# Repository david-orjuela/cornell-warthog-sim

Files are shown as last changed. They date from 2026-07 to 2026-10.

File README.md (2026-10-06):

# Cornell Warthog UR5e RGB-D Tree Reconstruction

A ROS 2 Humble system for repeatable RGB-D acquisition and colored point-cloud
reconstruction of orchard trees using a Clearpath Warthog, a UR5e arm, and an
eye-in-hand RealSense camera.

## Quickstart

> **Physical-robot warning:** the commands below can move a UR5e. Keep the
> teach pendant and emergency stop within reach, use the lab-approved start
> pose and calibration, verify clearances, and keep an experienced operator
> present. Never begin with an unattended 32-step run.

The field-validated system spans two ROS 2 workspaces:

- this repository provides the `reconstruct` package, capture transaction,
  raw-data preservation, reconstruction, and offline analyses;
- Dawood Ahmed's `tree_scanning_ur5e` repository provides the validated UR5e
  bringup, `recorded_scan_trajectory.json`, and
  `arm_scan_motion/scanning_trajectory` replay executable.

Clone both into the paths used by the tested commands:

```bash
mkdir -p "$HOME/dev"

git clone https://github.com/david-orjuela/cornell-warthog-sim.git \
  "$HOME/dev/cornell-warthog-sim"

git clone https://github.com/dahmedm/tree_scanning_ur5e.git \
  "$HOME/dev/dawood_tree_scanning_ur5e"
```

Build:

```bash
source /opt/ros/humble/setup.bash

cd "$HOME/dev/cornell-warthog-sim"
rosdep install --from-paths src --ignore-src --recursive --yes
python3 -m pip install -r requirements.txt
colcon build --symlink-install

cd "$HOME/dev/dawood_tree_scanning_ur5e"
rosdep install --from-paths src --ignore-src --recursive --yes
colcon build --symlink-install
```

Use a unique `scan_id` in
[`src/reconstruct/config/params.yaml`](src/reconstruct/config/params.yaml)
before every run. Never reuse an earlier dataset directory.

For the Cornell lab network, prepare each terminal in this order:

```bash
source /opt/ros/humble/setup.bash
source "$HOME/dev/cornell-warthog-sim/install/setup.bash"
source "$HOME/dev/dawood_tree_scanning_ur5e/install/setup.bash"
export ROS_DOMAIN_ID=26
```

Terminal 1 — bring up the real UR5e and leave it running:

```bash
ros2 launch arm_scan_motion bringup.launch.py
```

Terminal 2 — start reconstruction with wall-clock time:

```bash
ros2 launch reconstruct scan_tree.launch.py \
  params_file:="$HOME/dev/cornell-warthog-sim/src/reconstruct/config/params.yaml" \
  use_sim_time:=false
```

Terminal 3 — verify the controller and capture interfaces:

```bash
ros2 control list_controllers
ros2 action list -t | grep follow_joint_trajectory
ros2 topic info /tree_scan/capture_request -v
ros2 topic info /tree_scan/capture_result -v
```

Begin with a supervised one-step test:

```bash
ros2 run arm_scan_motion scanning_trajectory --ros-args \
  --params-file "$HOME/dev/cornell-warthog-sim/src/reconstruct/config/params.yaml" \
  -p trajectory_input_path:="$HOME/dev/dawood_tree_scanning_ur5e/recorded_scan_trajectory.json" \
  -p max_steps:=1
```

After validating the interfaces and robot behavior, stop the test, assign a new
`scan_id`, restart the reconstructor, and run the complete validated sequence:

```bash
ros2 run arm_scan_motion scanning_trajectory --ros-args \
  --params-file "$HOME/dev/cornell-warthog-sim/src/reconstruct/config/params.yaml" \
  -p trajectory_input_path:="$HOME/dev/dawood_tree_scanning_ur5e/recorded_scan_trajectory.json" \
  -p max_steps:=32
```

Inspect the result:

```bash
python3 -m json.tool "$HOME/dev/tree_scans/<scan_id>/summary.json"
ls -lh "$HOME/dev/tree_scans/<scan_id>/global_point_cloud.ply"
```

The launch file starts only the reconstructor. It does **not** launch the robot
driver or motion executor, and it has no `execute_motion` argument.

## Project background and authorship

This work was completed in summer 2026 by **David Orjuela**, a University of
Central Florida undergraduate visiting Cornell University's AgRobotics Lab
through an NSF-funded REU collaboration with UCF.

The project began with a broader orchard-simulation objective and then narrowed
to a hardware-first need: collect real leafy-tree geometry that could eventually
be cleaned, meshed, simplified, and used as Gazebo assets.

David inherited Dawood Ahmed's tree-scanning, reconstruction, semantic
segmentation, and skeletonization work. This repository adapts and extends the
geometry-reconstruction portion. Major contributions include:

- migration of the required acquisition and reconstruction path to ROS 2
  Humble;
- synchronized aligned RGB-D processing and TF2 lookup at sensor time;
- numbered move–settle–capture transactions;
- fresh five-frame, zero-aware depth bursts;
- retry and rejection handling that never merges failed attempts;
- raw RGB, depth, intrinsics, TF, joint-state, and point-cloud preservation;
- configurable filtering and bounded coarse-to-fine point-to-plane ICP;
- repeatable offline filter and registration experiments;
- TF-only, incremental ICP, scan-order, and TF-anchored pose-graph baselines;
- six orchard datasets with machine-readable summaries.

The dormant-tree semantic segmentation and skeletonization stages were reviewed
but were not migrated into the final field system. They remain inherited work,
not a claimed deliverable of this repository.

See [`docs/provenance.md`](docs/provenance.md) and
[`docs/inherited_work.md`](docs/inherited_work.md) before redistributing code,
calibration, models, imagery, or reconstructed assets.

## Final status

### Delivered

- [x] ROS 2 Humble aligned RGB-D reconstruction node
- [x] TF2 placement at each sensor timestamp
- [x] Metric colored Open3D point clouds and binary PLY export
- [x] Automated replay of the validated 32-pose UR5e trajectory
- [x] Numbered capture request/result handshake
- [x] Five-frame zero-aware depth bursts
- [x] Up to three fresh attempts at one stationary pose
- [x] Rejected-attempt isolation and preservation
- [x] Per-run configuration and summary JSON
- [x] Per-capture RGB, raw depth, median depth, intrinsics, TF, joint state,
      metadata, and raw camera/base-frame PLY output
- [x] Complete supervised indoor 32-pose reconstruction
- [x] Controlled filter and voxel comparisons from identical saved captures
- [x] TF-only and incremental TF+ICP controls
- [x] Incremental-ICP order-sensitivity experiment
- [x] TF-anchored pose-graph experiment with held-out edges
- [x] Six orchard datasets across five physical trees
- [x] Four complete 32-pose orchard runs and two recoverable partial runs
- [x] Dated technical logbook and operating documentation

### Still open

- [ ] Pin the exact external motion-repository URL, branch, and commit
- [ ] Verify the final `CMakeLists.txt` and `package.xml` from a clean clone
- [ ] Formally validate the camera-to-tool eye-in-hand transform
- [ ] Add acquisition-completeness and sun-corruption metrics
- [ ] Replay outdoor data with TF-only, incremental ICP, and the pose graph
- [ ] Add fixed spatial crops and thin cross-section measurements
- [ ] Validate and record the proposed 42-pose/four-row trajectory
- [ ] Record a complete rosbag audit trail for a future acquisition
- [ ] Mesh, simplify, and package selected trees for Gazebo
- [ ] Resolve licenses and approval for public code/data release

## Results

The month ended with a repeatable field system.

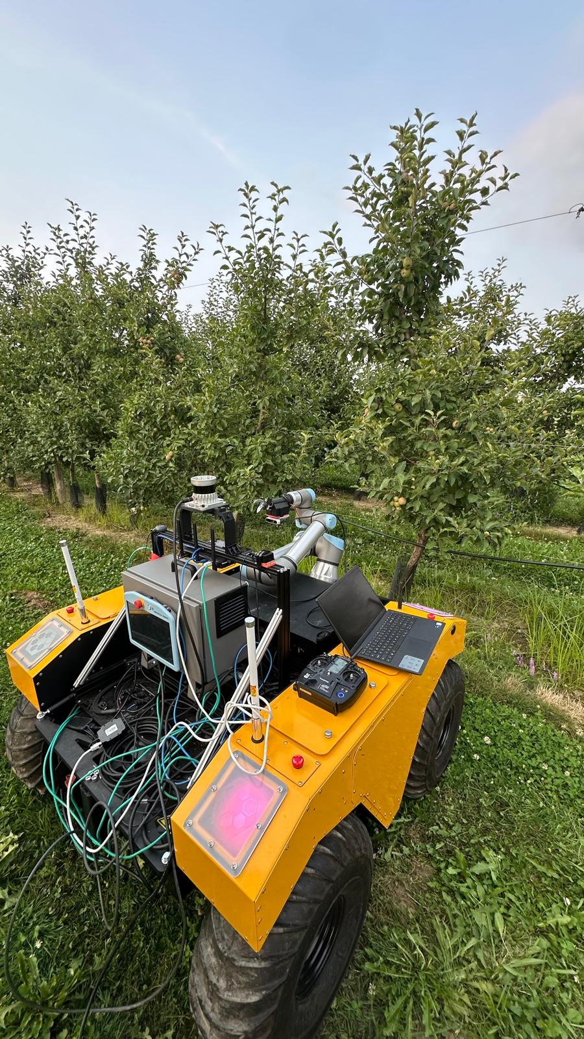
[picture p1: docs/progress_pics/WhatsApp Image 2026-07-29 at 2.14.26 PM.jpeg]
Warthog and UR5e in the Cornell orchard


UR5e performing the field raster scan

### Orchard deployment

Six datasets were collected across five physical trees. The reconstructor
accepted **155 of 157 pose requests** and processed **161 total attempts**.
Four datasets completed all 32 planned poses; two retained useful partial
results.

| Dataset | Pose requests | Accepted | Rejected attempts | Mean ICP fitness | Mean ICP RMSE | Final points | Outcome |
| --- | ---: | ---: | ---: | ---: | ---: | ---: | --- |
| `outdoor_tree_1` | 32 | 32 | 0 | 0.861 | 3.64 mm | 599,999 | Complete; away from sun |
| `outdoor_tree_2` | 32 | 32 | 0 | 0.915 | 3.39 mm | 664,476 | Complete but visually unusable; camera faced sun |
| `outdoor_tree_3` | 32 | 32 | 0 | 0.836 | 3.78 mm | 1,031,782 | Complete; away from sun |
| `outdoor_tree_4` | 14 | 12 | 6 | 0.802 | 4.24 mm | 660,495 | Partial; two poses exhausted all retries |
| `outdoor_tree_5` | 15 | 15 | 0 | 0.810 | 4.13 mm | 737,169 | Partial motion/run interruption |
| `outdoor_tree_6` | 32 | 32 | 0 | 0.862 | 3.78 mm | 1,505,222 | Successful repeat of the final tree |

The first five runs used `max_depth_m: 2.5`; `outdoor_tree_6` used 3.5 m.
All used five-frame depth bursts, at least two valid observations per pixel,
three attempts per pose, 3 mm local/global voxels, statistical outlier removal,
TF initialization, coarse-to-fine ICP, raw preservation, and final PLY export.

`outdoor_tree_2` is an important negative result. It achieved the best ICP
fitness and RMSE while direct sunlight destroyed much of the useful RealSense
depth. Registration metrics describe alignment of surviving points; they do
not prove target completeness or botanical correctness.

### Controlled filter comparison

The same saved 32-capture indoor scan was replayed so every profile used
identical robot poses and RGB-D observations. The table below is the original
6 mm local/5 mm global voxel comparison.

| Profile | Accepted | Final points | Mean fitness | Mean RMSE |
| --- | ---: | ---: | ---: | ---: |
| No outlier removal | 32/32 | 59,065 | 0.9197 | 3.755 mm |
| Current radius | 32/32 | 58,401 | 0.9193 | 3.754 mm |
| Dawood radius | 32/32 | 50,903 | 0.9178 | 3.905 mm |
| Statistical | 32/32 | 59,367 | 0.9206 | 3.731 mm |

The statistical profile had the strongest numerical result by a small margin.
The current-radius profile appeared to preserve slightly more useful fine plant
structure. Dawood's radius profile was too aggressive, and the unfiltered
result retained too much noise. The final field configuration used statistical
filtering at 3 mm local/global voxel size.

### Registration analysis

Good local ICP metrics did not imply a drift-free global reconstruction. In
the reported 4 mm local/global registration experiment, chronological
incremental ICP accepted all 32 captures, with approximately 0.927 mean fitness
and 3.32 mm mean RMSE, but the corrected poses increasingly departed from TF.

| Metric | Incremental TF + ICP | Nominal TF-anchored pose graph |
| --- | ---: | ---: |
| Mean translation deviation from TF | 5.30 mm | 1.99 mm |
| Maximum translation deviation from TF | 13.46 mm | 4.05 mm |
| Mean rotation deviation from TF | 1.01° | 0.108° |
| Maximum rotation deviation from TF | 1.94° | 0.198° |
| Translation-deviation trend | 0.264 mm/frame | approximately zero |
| Mean repeated-pose closure | 0.918 mm / 0.096° | 0.633 mm / 0.046° |
| Mean held-out pose residual | 4.17 mm / 0.686° | 2.91 mm / 0.607° |
| Held-out point-to-plane RMSE | 4.13 mm | 4.20 mm |

Changing only replay order caused mean pose changes of approximately 13.4 mm
and maximum changes near 20 mm. This demonstrated that accumulated-map ICP was
materially order-dependent.

The TF-anchored pose graph removed the frame-wise drift trend and improved pose
consistency, although incremental ICP retained a slightly lower held-out
surface RMSE. TF-only therefore remains a required control, and TEASER++ is
reserved for specific difficult pairwise edges rather than used as a blanket
replacement for the registration architecture.

## System design

```mermaid
flowchart TD
    A["UR5e trajectory reaches pose N"] --> B["Settle and publish UInt32 request N"]
    B --> C["Collect five fresh RGB-D + exact-TF samples"]
    C --> D["Save raw burst and build zero-aware median cloud"]
    D --> E{"Crop, filter, and bounded ICP accepted?"}
    E -->|Yes| F["Fuse cloud, save PLY, publish +N"]
    E -->|No; attempts remain| C
    E -->|No; attempts exhausted| G["Do not fuse; publish -N"]
```

The capture protocol is:

| Interface | Type | Meaning |
| --- | --- | --- |
| `/tree_scan/capture_request` | `std_msgs/msg/UInt32` | Positive pose/request ID |
| `/tree_scan/capture_result` | `std_msgs/msg/Int32` | `+N` accepted; `-N` rejected after all attempts |
| `/tree_scan/scan_finished` | `std_msgs/msg/Bool` | Finalize PLY and summary |
| `/tree_scan/latest_tf_cloud` | `sensor_msgs/msg/PointCloud2` | Current TF-placed, pre-ICP cloud |
| `/tree_scan/global_cloud` | `sensor_msgs/msg/PointCloud2` | Accumulated accepted reconstruction |

The active camera is `camera_jetson`, mounted on the UR5e end effector. It is
not the Warthog-front `camera_0`.

| Input | Validated Cornell topic |
| --- | --- |
| Color | `/sensors/camera_jetson/color/image_raw` |
| Aligned depth | `/sensors/camera_jetson/aligned_depth_to_color/image_raw` |
| Camera intrinsics | `/sensors/camera_jetson/aligned_depth_to_color/camera_info` |
| Robot joints | `/joint_states` |
| Dynamic/static transforms | `/tf`, `/tf_static` |
| Fixed reconstruction frame | `base_link` |

## Validated operating procedure

### 1. Use wall-clock time and the correct ROS domain

Hardware runs used:

```bash
export ROS_DOMAIN_ID=26
```

Keep `use_sim_time:=false` for the UR driver, controller manager, trajectory
controller, camera path, and reconstructor. A mixed clock domain invalidates
timestamped TF lookup.

### 2. Check camera delivery

```bash
ros2 topic hz /sensors/camera_jetson/color/image_raw
ros2 topic hz /sensors/camera_jetson/aligned_depth_to_color/image_raw
ros2 topic echo \
  /sensors/camera_jetson/aligned_depth_to_color/camera_info \
  --once
```

The aligned depth and color images must have matching dimensions. The current
node handles `16UC1` millimeter depth and `32FC1` meter depth.

### 3. Check exact-time TF and joint state

Get the actual depth message frame:

```bash
ros2 topic echo \
  /sensors/camera_jetson/aligned_depth_to_color/image_raw \
  --once \
  --field header.frame_id
```

Then verify:

```bash
ros2 run tf2_ros tf2_echo \
  base_link \
  camera_jetson_color_optical_frame

ros2 topic echo /joint_states --once
```

The joint-state message must contain all six UR5e joints.

### 4. Check the active controller

The field replay targeted:

```text
/joint_trajectory_controller/follow_joint_trajectory
```

Check it before every physical run:

```bash
ros2 control list_controllers
ros2 action list -t | grep follow_joint_trajectory
```

An action name can exist while its controller is inactive. Only one UR driver
and one controller manager should be running.

### 5. Test a stationary capture separately

Use a dedicated preflight `scan_id`, start the reconstructor, and listen for the
result:

```bash
ros2 topic echo /tree_scan/capture_result
```

In another terminal:

```bash
ros2 topic pub --once \
  /tree_scan/capture_request \
  std_msgs/msg/UInt32 \
  "{data: 1}"
```

Expected acceptance:

```text
data: 1
```

For a rejection, inspect:

```text
~/dev/tree_scans/<preflight_scan_id>/raw/capture_0001/capture.json
```

Do not reuse the preflight directory for the final 32-pose run.

### 6. Record an optional rosbag audit trail

The node's raw per-pose archive is sufficient for the provided offline
analyses. A rosbag additionally preserves the complete ROS traffic:

```bash
ros2 bag record \
  -o "$HOME/dev/tree_scans/raw_scan_$(date +%Y%m%d_%H%M%S)" \
  /sensors/camera_jetson/color/image_raw \
  /sensors/camera_jetson/aligned_depth_to_color/image_raw \
  /sensors/camera_jetson/aligned_depth_to_color/camera_info \
  /tf \
  /tf_static \
  /joint_states \
  /tree_scan/capture_request \
  /tree_scan/capture_result \
  /tree_scan/scan_finished
```

### 7. End and verify the run

When the motion executor publishes `/tree_scan/scan_finished`, the reconstructor
writes the final PLY and summary. If a run is interrupted, stop the
reconstructor cleanly with `Ctrl-C`; its shutdown path also writes the current
PLY and summary.

Verify:

```bash
python3 -m json.tool "$HOME/dev/tree_scans/<scan_id>/summary.json"
find "$HOME/dev/tree_scans/<scan_id>/raw" \
  -maxdepth 2 \
  -name capture.json \
  -print
```

`summary.json` reports attempt-based `accepted_percent`. Use
`accepted_capture_requests / completed_capture_requests` for pose-request
success.

## Output layout

```text
~/dev/tree_scans/<scan_id>/
├── global_point_cloud.ply
├── run_config.json
├── summary.json
└── raw/
    ├── capture_0001/
    │   ├── capture.json
    │   ├── frame_00_color.png
    │   ├── frame_00_depth.npy
    │   ├── frame_00_depth.png
    │   ├── ...
    │   ├── selected_color.png
    │   ├── median_depth_m.npy
    │   ├── median_depth_mm.png
    │   ├── median_valid_counts.npy
    │   ├── raw_camera_cloud.ply
    │   └── raw_target_cloud.ply
    └── capture_0001_attempt_02/
        └── ...
```

Every attempt is preserved separately. Only accepted attempts are merged into
`global_point_cloud.ply`.

`capture.json` records:

- request and attempt IDs;
- acceptance state and reason;
- camera intrinsics and encodings;
- every sensor timestamp;
- exact `target_frame <- camera_frame` matrices;
- joint-state snapshots;
- burst pose spread;
- valid-depth fraction;
- raw, cropped, filtered, and global point counts;
- crop bounds;
- ICP fitness, RMSE, and correction;
- processing time.

`run_config.json` preserves the effective ROS parameters used for acquisition.
Offline scripts read this file, not the repository's current `params.yaml`.

## Offline evaluation

No ROS nodes or robot hardware are required after acquisition.

### Filter and TF/ICP comparison

```bash
python3 src/reconstruct/scripts/compare_filters.py \
  "$HOME/dev/tree_scans/<scan_id>" \
  --profiles none current_radius dawood_radius statistical \
  --registration-modes tf_only tf_icp \
  --local-voxel-size-m 0.003 \
  --global-voxel-size-m 0.003
```

Default output:

```text
<scan_id>/filter_comparisons/<timestamp>_voxel_3mm_local_3mm_global/
```

Key outputs are `comparison.csv`, `replay_manifest.json`, per-frame metrics,
closure metrics, diagnostic plots, and one PLY per filter/registration mode.

### Registration experiment

Fast smoke test:

```bash
python3 src/reconstruct/scripts/compare_registration.py \
  "$HOME/dev/tree_scans/<scan_id>" \
  --profiles statistical \
  --graph-priors nominal \
  --shuffle-count 1
```

Full indoor experiment with known repeated poses:

```bash
python3 src/reconstruct/scripts/compare_registration.py \
  "$HOME/dev/tree_scans/indoor_model_tree_2" \
  --profiles statistical \
  --closure-pairs 3:12,13:22,23:32 \
  --local-voxel-size-m 0.004 \
  --global-voxel-size-m 0.004
```

If request IDs differ, omit `--closure-pairs`; the script attempts automatic
TF-based detection.

See
[`docs/evaluation/REGISTRATION_EVALUATION.md`](docs/evaluation/REGISTRATION_EVALUATION.md)
for outputs and interpretation. Run either analysis script with `--help` for
its complete CLI.

## Configuration

The checked-in
[`src/reconstruct/config/params.yaml`](src/reconstruct/config/params.yaml)
contains the final field-era configuration. The most consequential values are:

| Parameter | Field value | Purpose |
| --- | ---: | --- |
| `depth_burst_size` | 5 | Fresh samples at each stationary pose |
| `depth_burst_min_valid_samples` | 2 | Minimum nonzero observations per pixel |
| `capture_max_attempts` | 3 | Fresh bursts before final rejection |
| `capture_retry_delay_sec` | 0.25 s | Delay between attempts |
| `min_depth_m` | 0.30 m | Conservative D435 validity guard |
| `max_depth_m` | 3.50 m | Final field range; first five runs used 2.50 m |
| `local_voxel_size_m` | 0.003 m | Per-capture downsampling |
| `global_voxel_size_m` | 0.003 m | Accumulated-cloud downsampling |
| `outlier_filter_mode` | `statistical` | Final field filter |
| `use_icp` | `true` | TF placement followed by bounded refinement |
| `capture_timeout_sec` | 60 s | Includes reconstruction-side retries |
| `abort_on_capture_rejection` | `false` | Preserve partial scans after a failed pose |

The full reference, including every reconstructor, registration-scale, replay,
and analysis option, is in
[`docs/PARAMETER_REFERENCE.md`](docs/PARAMETER_REFERENCE.md).

## Repository map

| Path | Status | Purpose |
| --- | --- | --- |
| `README.md` | Active | Clone/build/run/results entry point |
| `requirements.txt` | Active | Tested non-ROS Python dependencies |
| `src/reconstruct/scripts/pointcloud_processing.py` | Active | Capture-triggered ROS 2 RGB-D reconstruction node |
| `src/reconstruct/reconstruct/pc_utils.py` | Active | Open3D-to-ROS 2 `PointCloud2` conversion |
| `src/reconstruct/launch/scan_tree.launch.py` | Active | Loads the reconstructor and parameter file |
| `src/reconstruct/config/params.yaml` | Active | Reconstructor and motion-handshake configuration |
| `src/reconstruct/scripts/compare_filters.py` | Active offline tool | Same-capture filter and TF/ICP replay |
| `src/reconstruct/scripts/compare_registration.py` | Active research tool | Order tests and TF-anchored pose-graph comparison |
| `src/reconstruct/scripts/motion_planner.py` | Experimental; archive | Unvalidated cuRobo migration using the obsolete `/capture_alert` protocol |
| `src/reconstruct/scripts/old_pointcloud_processing.py` | Legacy; archive | Earlier reconstruction implementation; not the field node |
| `src/reconstruct/scripts/REGISTRATION_EVALUATION.md` | Move/replace | Superseded by `docs/evaluation/REGISTRATION_EVALUATION.md` |
| `src/reconstruct/README.md` | Active package guide | Package-specific interfaces and commands |
| `ros1-reconstruction/` | Frozen legacy | Original ROS 1 material; ignored by colcon |
| `docs/IMPLEMENTATION_GUIDE.md` | Active deep guide | Capture design, raw archive, crop, clock, calibration, and controller notes |
| `docs/PARAMETER_REFERENCE.md` | Active | Complete parameter and analysis CLI reference |
| `docs/HANDOFF_CHECKLIST.md` | Active until final tag | Cleanup, provenance, clean-clone, and release checks |
| `docs/evaluation/REGISTRATION_EVALUATION.md` | Active | Registration experiment procedure and outputs |
| `docs/logbook/` | Historical evidence | Dated development, debugging, and field notes |
| `docs/project_charter.md` | Historical planning snapshot | July 21 scope; final outcome is documented here |
| `docs/migration_inventory.md` | Historical migration snapshot | ROS 1/ROS 2 and inherited-work inventory |
| `docs/inherited_work.md` | Active provenance | Ownership and disposition of inherited components |
| `docs/provenance.md` | Active provenance | Sources, authorship, licensing, and release questions |
| `docs/archive/` | Historical | Superseded plans and handoff questions |
| `docs/progress_pics/` | Curated documentation media | Robot, reconstruction, and field evidence |

`CMakeLists.txt`, `package.xml`, `resource/reconstruct`, and
`reconstruct/__init__.py` are ROS 2 package/build metadata. Verify them through
the clean-clone test in the handoff checklist.

## Troubleshooting

### Capture request is published but no result arrives

1. Confirm all three RGB-D inputs are publishing.
2. Confirm their timestamps advance and their dimensions match.
3. Verify exact-time TF from `base_link` to the camera optical frame.
4. Check laptop/Jetson clock synchronization.
5. Allow the configured 60 seconds for all three attempts.
6. Inspect the newest `capture.json` and reconstructor log.

Earlier 15–20 second motion-side timeouts were shorter than a full retry cycle;
one measured final response arrived after approximately 22.8 seconds.

### `TF unavailable` or no base-frame cloud

- use `ROS_DOMAIN_ID=26` on the Cornell system;
- confirm the robot driver and `/joint_states` are running;
- do not treat a frame ID as a topic name;
- verify `/tf` and `/tf_static`;
- run `tf2_echo base_link camera_jetson_color_optical_frame`;
- keep every hardware process on wall time.

For camera-only debugging, `target_frame` may temporarily equal the camera
optical frame; the reconstructor then uses an identity transform. Do not use
that mode for moving-arm fusion.

### Empty or incomplete close-range cloud

The D435 has a practical minimum range. The software guard is 0.30 m. If near
geometry disappears, inspect the aligned depth image and move the camera back
before changing registration settings.

### Open3D depth-image dtype error

The active node uses NumPy pinhole back-projection and supports native-endian
`16UC1` and `32FC1` inputs. If an Open3D image-construction dtype error returns,
the old reconstruction script is probably being run. Check:

```bash
ros2 pkg prefix reconstruct
ros2 pkg executables reconstruct
```

Rebuild and source the active workspace.

### Capture pipeline is not connected

Start the reconstructor before a capture-enabled trajectory replay. For a
motion-only test, explicitly set:

```bash
-p capture_enabled:=false
```

### Trajectory action exists but motion fails

An action name does not prove the controller is active:

```bash
ros2 control list_controllers
ros2 action list -t | grep follow_joint_trajectory
```

The validated replay used `joint_trajectory_controller`. Do not switch to a
scaled or passthrough controller without a separate supervised motion-system
test.

### Trajectory times out at a low pendant speed

The final configuration allows up to ten times nominal duration plus ten
seconds. Increasing `pause_ms` does not change a trajectory segment's internal
timestamps and is not a substitute for correct timing.

### Direct sunlight produces a dense but bad reconstruction

This is an acquisition-completeness failure, not an ICP failure. Orient the
camera away from the sun, inspect valid-depth coverage before motion, and retain
the failed run as a labeled negative control.

### Filter experiment does not change after editing `params.yaml`

Offline replay intentionally reads the acquisition-time `run_config.json`.
Pass `--local-voxel-size-m` and `--global-voxel-size-m` to override values for
an experiment. Never overwrite the original `run_config.json`.

### PLY is dark in MeshLab

The final PLY stores per-vertex RGB. In MeshLab, disable vertex shading
(`Shading: None`) to avoid lighting that makes the cloud appear nearly black.

### Warthog Wi-Fi and Internet become unusably slow

The lab diagnosis found approximately 250–290 Mb/s of continuous uncompressed
RGB/depth traffic saturating the wireless link. Stop unnecessary RGB-D
subscribers and duplicate ROS processes, use Ethernet for robot traffic where
possible, retain Eduroam as the Internet route, reduce unused stream rates, and
prefer discrete capture over continuous visualization.

### Duplicate or stale ROS nodes

Only one UR driver, one controller manager, one reconstructor, and one motion
executor should be active. Stop known launch terminals with `Ctrl-C`, then
inspect:

```bash
ros2 node list
ps -ef | grep -E 'ros2|pointcloud_processing|scanning_trajectory'
```

Do not kill unrelated system processes blindly.

### `No executable found` for `scanning_trajectory_node`

The field-validated executable is `scanning_trajectory`. The separate
trajectory generator source must be registered in `arm_scan_motion`'s
`CMakeLists.txt` before ROS can run it. The proposed 42-step trajectory was not
part of the final validated field path.

## Known limitations

- The physical RealSense-to-tool transform was CAD-derived but not formally
  validated through eye-in-hand calibration.
- Incremental frame-to-accumulated-map ICP is order-dependent.
- The first pose-graph experiment improved pose consistency but was not a
  definitive visual-quality winner.
- ICP fitness, RMSE, and final point count do not measure tree completeness.
- Direct sun can invalidate depth while conventional registration metrics stay
  excellent.
- The 32-pose scan emphasizes frontal coverage and lacks strong side-view
  parallax.
- Thin leaves and partially occluded fruit remain difficult for the D435.
- The target-relative crop exists but remained disabled in the reported field
  runs.
- The system exports point clouds, not finished watertight meshes or Gazebo
  models.
- Complete reproduction depends on the external motion repository and recorded
  trajectory file.

## Next research

1. Replay complete away-from-sun orchard datasets with TF-only, chronological
   incremental ICP, reverse/shuffled ICP, and the TF-anchored pose graph.
2. Add acquisition-completeness metrics before registration:
   valid-depth percentage in a target ROI, invalid/saturated pixel rate,
   target-point counts, distance distributions, and spatial contribution
   coverage.
3. Compare identical fixed crops and thin cross-sections through trunks,
   branch junctions, apples, and leaves.
4. Quantify shell thickness, duplicate surfaces, capture-to-capture spread, and
   local geometric residuals.
5. Validate the camera-to-tool transform with a fixed calibration target and
   diverse arm orientations.
6. Improve high and oblique coverage, then safely validate the proposed
   four-row/42-step path.
7. Use TEASER++ only for a verified overlapping edge that repeatedly defeats
   robust TF-initialized ICP.
8. Select promising complete scans, remove background, estimate normals, mesh,
   repair, simplify, and create separate visual/collision assets for Gazebo.

## Documentation index

- [`docs/IMPLEMENTATION_GUIDE.md`](docs/IMPLEMENTATION_GUIDE.md) — detailed
  acquisition, crop, sensor, timing, controller, and calibration guidance.
- [`docs/PARAMETER_REFERENCE.md`](docs/PARAMETER_REFERENCE.md) — complete
  configuration reference.
- [`docs/evaluation/REGISTRATION_EVALUATION.md`](docs/evaluation/REGISTRATION_EVALUATION.md)
  — registration experiment guide.
- [`docs/HANDOFF_CHECKLIST.md`](docs/HANDOFF_CHECKLIST.md) — final repository
  cleanup and verification.
- [`docs/logbook/`](docs/logbook/) — dated technical record; useful for
  rationale and debugging history, not required reading for normal operation.
- [`docs/provenance.md`](docs/provenance.md) — source, authorship, licensing,
  and release constraints.

## Data, licensing, and release

Generated RGB-D arrays, rosbags, PLY files, comparison outputs, and full
datasets are intentionally excluded from normal Git history. Preserve each
dataset with its `run_config.json`, `summary.json`, per-capture metadata, source
commit, operator, date, location/tree ID, hardware/calibration references, and
checksums in lab-approved storage.

No public-use license should be inferred merely because the repository is
visible. Dawood's inherited code, Cornell lab assets, robot calibration,
orchard imagery, third-party models, and generated datasets may have different
ownership and release constraints. Resolve the open questions in
[`docs/provenance.md`](docs/provenance.md) before publishing or redistributing
the repository or data.

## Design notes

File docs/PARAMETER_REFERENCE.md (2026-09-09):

# Parameter Reference

This document describes the final summer 2026 configuration supplied with the
repository. It distinguishes:

- the effective values in `src/reconstruct/config/params.yaml`;
- the Python reconstructor's internal defaults;
- parameters consumed by the external `arm_scan_motion` executables;
- command-line options for the two offline analysis scripts.

For a completed dataset, `run_config.json` is the authoritative record of the
parameters actually used. Editing the repository YAML after acquisition does
not change an existing dataset.

## Launch arguments

`src/reconstruct/launch/scan_tree.launch.py` declares:

| Argument | Default | Meaning |
| --- | --- | --- |
| `params_file` | Installed `share/reconstruct/config/params.yaml` | Parameter file passed to the reconstructor |
| `use_sim_time` | `false` | Overrides the node's clock setting |

The launch file starts only `tree_point_cloud_reconstructor`. It does not have
an `execute_motion` argument.

## `tree_point_cloud_reconstructor`

### Clock and input topics

| Parameter | Supplied value | Meaning |
| --- | --- | --- |
| `use_sim_time` | `false` | Use wall time on physical hardware |
| `color_topic` | `/sensors/camera_jetson/color/image_raw` | UR5e-mounted RealSense color |
| `depth_topic` | `/sensors/camera_jetson/aligned_depth_to_color/image_raw` | Depth aligned to color |
| `camera_info_topic` | `/sensors/camera_jetson/aligned_depth_to_color/camera_info` | Intrinsics matching aligned depth |
| `joint_state_topic` | `/joint_states` | Snapshot source saved with each frame |

`camera_jetson` is the eye-in-hand camera. `camera_0` is the Warthog-front
camera and is not the validated reconstruction input.

### Capture and output topics

| Parameter | Supplied value | Meaning |
| --- | --- | --- |
| `capture_request_topic` | `/tree_scan/capture_request` | `UInt32` pose/request ID |
| `capture_result_topic` | `/tree_scan/capture_result` | `Int32`; `+N` accepted, `-N` rejected |
| `scan_finished_topic` | `/tree_scan/scan_finished` | `Bool` completion notice |
| `output_cloud_topic` | `/tree_scan/global_cloud` | Accumulated accepted cloud |
| `original_cloud_topic` | `/tree_scan/latest_tf_cloud` | Latest cropped TF-placed cloud before ICP |

### Frames and output paths

| Parameter | Supplied value | Meaning |
| --- | --- | --- |
| `target_frame` | `base_link` | Fixed frame for moving-arm reconstruction |
| `camera_frame_override` | empty | Use the depth/camera-info message frame |
| `output_root` | `~/dev/tree_scans` | Root directory for generated datasets |
| `scan_id` | `example_scan` | Dataset directory name; change for every run |
| `capture_on_start` | `false` | Wait for a numbered request rather than capturing immediately |

Do not commit a field dataset name such as `outdoor_tree_6` as the reusable
default. A repeated `scan_id` mixes attempts from different runs.

### RGB-D synchronization and timing

| Parameter | Supplied value | Meaning |
| --- | ---: | --- |
| `sync_queue_size` | 30 | Approximate-time synchronizer queue |
| `sync_slop_sec` | 0.08 s | Maximum synchronization slop |
| `tf_timeout_sec` | 0.75 s | Exact-time TF lookup timeout |
| `post_request_guard_sec` | 0.0 s | Additional age guard after the request |
| `sensor_clock_warning_sec` | 0.25 s | Warn when sensor stamp and local clock differ by more than this |

The code always rejects synchronized frames at or before the pose-specific
request time. The clock warning includes transport latency and is diagnostic,
not an automatic rejection.

### Depth burst and retry policy

| Parameter | Supplied value | Meaning |
| --- | ---: | --- |
| `depth_burst_size` | 5 | Fresh synchronized samples per attempt |
| `depth_burst_min_valid_samples` | 2 | Minimum nonzero observations required per pixel |
| `capture_max_attempts` | 3 | Fresh bursts allowed at one pose |
| `capture_retry_delay_sec` | 0.25 s | Delay before collecting the next burst |
| `burst_pose_translation_tolerance_m` | 0.005 m | Maximum translation spread inside a burst |
| `burst_pose_rotation_tolerance_deg` | 0.5° | Maximum rotation spread inside a burst |

The median ignores zero/invalid depth. A rejected attempt is saved but never
merged. A negative result is published only after all attempts fail.

### Depth range and units

| Parameter | Supplied value | Meaning |
| --- | ---: | --- |
| `min_depth_m` | 0.30 m | Conservative D435 near-range guard |
| `max_depth_m` | 3.50 m | Broad final field range |
| `depth_scale_override` | 0.0 | Automatic: 1000 units/m for `16UC1`, 1 for `32FC1` |

The first five orchard datasets used `max_depth_m: 2.50`. `outdoor_tree_6`
used 3.50 m. The range limits are sensor guards; they are not a tree-specific
scene crop.

### Target-relative crop

| Parameter | Supplied value | Meaning |
| --- | --- | --- |
| `target_crop_enabled` | `false` | Disable the fixed base-frame crop |
| `target_center_mode` | `camera_forward` | `camera_forward` or `fixed_target_frame` |
| `target_distance_m` | 1.0 m | First-pose optical-axis distance used by `camera_forward` |
| `target_center_target_frame_m` | `[0.0, 0.0, 0.0]` | Explicit center for `fixed_target_frame` |
| `target_box_size_m` | `[1.0, 1.0, 1.5]` | Base-frame X/Y/Z box dimensions |

In `camera_forward` mode, the first accepted burst projects
`[0, 0, target_distance_m]` through the recorded camera transform and locks
that base-frame center for the entire scan. Later camera motion does not move
the crop.

The reported field runs left this feature disabled. Measure the target and test
on saved data before enabling it during acquisition.

### Downsampling and outlier filtering

| Parameter | Supplied value | Meaning |
| --- | ---: | --- |
| `local_voxel_size_m` | 0.003 m | Per-capture voxel downsampling |
| `global_voxel_size_m` | 0.003 m | Accumulated-cloud voxel downsampling |
| `outlier_removal_enabled` | `true` | Enable the selected outlier stage |
| `outlier_filter_mode` | `statistical` | `none`, `radius`, or `statistical` |
| `outlier_radius_m` | 0.020 m | Radius-filter neighborhood |
| `outlier_min_neighbors` | 6 | Radius-filter minimum count |
| `statistical_nb_neighbors` | 20 | Statistical-filter neighborhood size |
| `statistical_std_ratio` | 2.0 | Statistical outlier threshold |

Radius parameters remain in the file so saved data can be replayed with the
`current_radius` profile. They are inactive while the live mode is
`statistical`.

### ICP and fusion

| Parameter | Supplied value | Meaning |
| --- | ---: | --- |
| `use_icp` | `true` | Apply multiscale ICP after TF placement |
| `icp_crop_margin_m` | 0.15 m | Margin around the source bounds for the local target |
| `icp_min_target_points` | 200 | Fall back to the full global map below this count |
| `max_icp_correction_translation_m` | 0.10 m | Reject implausibly large ICP translations |
| `max_icp_correction_rotation_deg` | 12.0° | Reject implausibly large ICP rotations |

ICP is a bounded refinement, not a replacement for TF or calibration. The
10 cm/12° guards were retained until the eye-in-hand transform can be formally
validated. Future experiments may evaluate approximately 3 cm/5° after
calibration.

### Persistence and lifecycle

| Parameter | Supplied value | Meaning |
| --- | --- | --- |
| `save_raw_point_clouds` | `true` | Save raw camera- and target-frame PLYs |
| `publish_original_cloud` | `true` | Publish the latest TF-placed cloud |
| `shutdown_on_scan_finished` | `false` | Save on completion but keep the node alive |

Regardless of `save_raw_point_clouds`, the code saves the raw RGB/depth burst,
median arrays, intrinsics, TF, joint-state snapshots, and metadata. This flag
controls the two raw PLY files.

## Registration scales

Every scale uses point-to-plane ICP. Thresholds are checked after each scale;
failure at an early scale rejects the attempt.

| Scale | Voxel | Correspondence | Iterations | Relative RMSE | Relative fitness | RMSE ceiling | Fitness floor |
| --- | ---: | ---: | ---: | ---: | ---: | ---: | ---: |
| `SN3` | 0.050 m | 0.050 m | 50 | `1e-6` | `1e-6` | 0.025 m | 0.35 |
| `SN2` | 0.020 m | 0.030 m | 30 | `1e-6` | `1e-6` | 0.015 m | 0.40 |
| `SN1` | 0.010 m | 0.018 m | 20 | `1e-6` | `1e-6` | 0.010 m | 0.45 |
| `SN0` | no voxel | 0.012 m | 15 | `1e-6` | `1e-6` | 0.008 m | 0.45 |

The final `SN0` fitness floor was reduced from 0.50 to 0.45 for more variable
orchard overlap while retaining the 8 mm RMSE ceiling, stricter coarse stages,
and correction sanity bounds.

Each scale is represented by:

```text
registration.<scale>.voxel_size_m
registration.<scale>.max_correspondence_distance_m
registration.<scale>.max_iterations
registration.<scale>.relative_rmse
registration.<scale>.relative_fitness
registration.<scale>.rmse_threshold_m
registration.<scale>.fitness_threshold
```

## `scanning_trajectory`

This section is consumed by the field-validated JSON replay executable in the
external `arm_scan_motion` package.

| Parameter | Supplied value | Meaning |
| --- | ---: | --- |
| `capture_enabled` | `true` | Use the reconstruction handshake |
| `capture_request_topic` | `/tree_scan/capture_request` | Numbered request |
| `capture_result_topic` | `/tree_scan/capture_result` | Signed result |
| `scan_finished_topic` | `/tree_scan/scan_finished` | Completion output |
| `capture_settle_time_ms` | 250 ms | Wait after successful motion |
| `capture_timeout_sec` | 60.0 s | Includes all reconstructor retry attempts |
| `capture_subscriber_timeout_sec` | 30.0 s | Wait for the reconstructor to connect |
| `abort_on_capture_rejection` | `false` | Preserve a partial scan and continue after `-N` |
| `trajectory_timeout_scale` | 10.0 | Multiplier on nominal segment duration |
| `trajectory_timeout_margin_sec` | 10.0 s | Additional segment timeout |
| `max_steps` | 0 in YAML | Pass 1 for preflight or 32 for the validated full replay |
| `pause_ms` | 300 ms | Inter-segment pause |

Known external runtime overrides:

| Parameter | Validated use |
| --- | --- |
| `trajectory_input_path` | Absolute path to `recorded_scan_trajectory.json` |
| `max_steps` | Explicitly set to `1` during preflight and `32` for the final run |
| `capture_enabled` | Set `false` only for a motion-only test |

The external C++ source was not included in the documentation audit, so this
table claims only the supplied YAML values and the runtime overrides verified
in the project notes. Inspect the pinned C++ source or run `ros2 param list`
for any additional declarations.

## `scanning_trajectory_node`

This section configures the separate MoveIt waypoint/trajectory-recording
executable. It was not the final field replay path.

| Parameter | Supplied value | Meaning |
| --- | ---: | --- |
| `capture_enabled` | `true` | Enable capture handshake |
| `capture_request_topic` | `/tree_scan/capture_request` | Numbered request |
| `capture_result_topic` | `/tree_scan/capture_result` | Signed result |
| `scan_finished_topic` | `/tree_scan/scan_finished` | Completion output |
| `capture_settle_time_ms` | 1000 ms | Settle time during generated motion |
| `capture_timeout_sec` | 60.0 s | Wait through retries |
| `capture_subscriber_timeout_sec` | 30.0 s | Wait for reconstructor |
| `abort_on_capture_rejection` | `false` | Do not abort on one exhausted pose |

The proposed four-row generator could produce a 42-step trajectory with
0.15 m row spacing, ±0.15 m lateral positions, and a 15° look angle. That path
remained future work and must not be represented as field-validated.

## `compare_filters.py`

Run:

```bash
python3 src/reconstruct/scripts/compare_filters.py --help
```

| Argument | Default | Meaning |
| --- | --- | --- |
| `scan_dir` | required | Dataset with `run_config.json` and `raw/capture_*` |
| `--profiles` | all four | `none`, `current_radius`, `dawood_radius`, `statistical` |
| `--output-dir` | timestamped directory under the scan | Explicit output root |
| `--no-icp` | false | Deprecated shortcut for TF-only; cannot combine with `--registration-modes` |
| `--registration-modes` | `tf_only tf_icp` | Registration variants |
| `--local-voxel-size-m` | saved value | Override local voxel size |
| `--global-voxel-size-m` | saved value | Override global voxel size |
| `--closure-pairs` | auto-detect | Comma-separated request pairs such as `3:12,13:22,23:32` |
| `--closure-translation-tolerance-m` | 0.005 m | Auto-detection translation tolerance |
| `--closure-rotation-tolerance-deg` | 1.0° | Auto-detection rotation tolerance |
| `--closure-min-frame-gap` | 8 | Minimum capture-index separation |

Filter profiles:

| Profile | Voxel | Outlier stage |
| --- | --- | --- |
| `none` | Current/overridden local voxel | None |
| `current_radius` | Current/overridden local voxel | Current radius and neighbor settings |
| `dawood_radius` | 0.008 m | 8 neighbors inside 0.014 m |
| `statistical` | Current/overridden local voxel | Current statistical settings |

The `none` profile still applies crop, voxelization, optional ICP, and global
voxelization. It disables only outlier removal.

## `compare_registration.py`

Run:

```bash
python3 src/reconstruct/scripts/compare_registration.py --help
```

### Source, profile, and closure options

| Argument | Default | Meaning |
| --- | --- | --- |
| `scan_dir` | required | Saved dataset |
| `--profiles` | `statistical` | Filter profiles to evaluate |
| `--output-dir` | `<scan>/registration_comparisons/<timestamp>` | Output root |
| `--local-voxel-size-m` | saved value | Override all variants |
| `--global-voxel-size-m` | saved value | Override all variants |
| `--closure-pairs` | auto-detect | Repeated-pose request pairs |
| `--closure-translation-tolerance-m` | 0.005 m | Auto-detection translation tolerance |
| `--closure-rotation-tolerance-deg` | 1.0° | Auto-detection rotation tolerance |
| `--closure-min-frame-gap` | 8 | Minimum separation for closure detection |

### Incremental-order options

| Argument | Default | Meaning |
| --- | --- | --- |
| `--skip-order-test` | false | Skip reverse and shuffled incremental replays |
| `--shuffle-count` | 3 | Deterministic shuffled replays |
| `--random-seed` | 23 | Shuffle and held-out-edge seed |

### TF-anchored pose-graph options

| Argument | Default | Meaning |
| --- | --- | --- |
| `--graph-priors` | `loose nominal strong` | TF-prior sweep |
| `--graph-scales` | `SN2 SN1 SN0` | Pairwise edge ICP scales |
| `--graph-min-aabb-overlap` | 0.05 | Minimum AABB intersection/min-volume ratio |
| `--graph-extra-neighbors` | 3 | Maximum extra overlap candidates per capture |
| `--graph-holdout-fraction` | 0.20 | Extra edges excluded from optimization |
| `--graph-max-correction-translation-m` | 0.030 m | Maximum edge departure from relative TF |
| `--graph-max-correction-rotation-deg` | 5.0° | Maximum edge departure from relative TF |
| `--robust-kernel-k-fraction` | 0.5 | Tukey-k fraction of correspondence distance |
| `--robust-kernel-min-m` | 0.004 m | Minimum Tukey-k |
| `--graph-edge-information-scale` | 1.0 | Geometric information multiplier |
| `--graph-edge-prune-threshold` | 0.25 | Open3D uncertain-edge prune threshold |
| `--graph-loop-closure-preference` | 1.0 | Certain/uncertain edge balance |

TF-prior presets are experimental weights, not measured calibration
covariances:

| Preset | Translation sigma | Rotation sigma |
| --- | ---: | ---: |
| `loose` | 20 mm | 2.0° |
| `nominal` | 10 mm | 1.0° |
| `strong` | 5 mm | 0.5° |

### Evaluation and visualization options

| Argument | Default | Meaning |
| --- | --- | --- |
| `--evaluation-voxel-size-m` | 0.010 m | Held-out geometric evaluation voxel |
| `--evaluation-max-distance-m` | 0.025 m | Nearest-neighbor evaluation limit |
| `--evaluation-trim-fraction` | 0.90 | Lowest residual fraction retained |
| `--skip-visuals` | false | Skip fixed-view comparison PNGs |
| `--visual-max-points` | 150,000 | Maximum plotted points per variant |

Keep `--graph-scales` ordered coarse-to-fine. Do not relax the 30 mm/5° edge
guards merely to make more edges pass; inspect overlap, crop, and calibration
first.

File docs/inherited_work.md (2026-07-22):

# Inherited Work Register

## Purpose

This is the operational register for inherited code and assets. It answers a different question from `provenance.md`:

> What should be done with each inherited component under the current reconstruction-focused scope?

For authorship, licensing, and chain-of-custody details, use `provenance.md`.

---

## Disposition Categories

- **Active — adapt:** required for the current deliverable and being changed now.
- **Active dependency:** required, but maintained primarily upstream or by the lab.
- **Preserve — downstream:** not part of the immediate milestone, but likely needed after reconstruction succeeds.
- **Preserve — decision required:** conflicting or ambiguous inherited work that must not be overwritten.
- **Archive:** useful evidence, historical work, or generated output; not active source.
- **Exclude from current scope:** do not spend time on it unless the project is redirected.

---

## Register

| Component | Immediate source | Current interpretation | Disposition | Priority / next action |
| --- | --- | --- | --- | --- |
| Dawood `motion_planner.py` | Dawood reconstruction repository | ROS 1 UR5e + cuRobo control with hardcoded scan/pruning behavior and unsafe assumptions | **Active — adapt** | Validate ROS 2 action namespace, six-joint state source, cuRobo configs, quaternion convention, raster axes, and dry-run behavior |
| Dawood `pointcloud_processing.py` | Dawood reconstruction repository | Core synchronized RGB-D, TF, Open3D, ICP, filtering, fusion, metrics, and publishing logic | **Active — adapt** | Produce one stationary ROS 2 PLY, then two-view and small-raster validation |
| Dawood `pc_utils.py` | Dawood reconstruction repository | Shared point-cloud conversion and clustering helpers; ROS 1 conversion dependency | **Active — adapt** | Retain useful geometry helpers; consolidate duplicate conversion code; validate ROS 2 `PointCloud2` output |
| Dawood ROS 1 package/launch files | Dawood reconstruction repository | Catkin, `rospy`, ROS 1 actions/services/TF, old topic paths | **Archive after migration** | Keep for traceability; do not run as the active Warthog implementation |
| YOLO segmentation integration | Dawood reconstruction repository | Dormant-tree trunk/branch instance-mask coloring | **Preserve — downstream / optional** | Bypass for initial leafy geometry; revisit only for vegetation/background separation or structural analysis |
| BiSeNet integration | Dawood reconstruction repository | Alternative dormant-tree semantic segmentation | **Archive / optional** | Do not migrate until there is a demonstrated need and model/license provenance is known |
| YOLO/BiSeNet model weights | External files used by Dawood's pipeline | Required only for semantic modes | **Preserve — decision required** | Verify ownership, training data, version, and license before copying into a new repository |
| `skeletonization.py` | Dawood reconstruction repository | DBSCAN and spline-based trunk/branch hierarchy extraction | **Archive / optional** | Exclude from geometry-first scan; reconsider for procedural collision geometry or horticultural measurements |
| `tree_component.py` | Dawood reconstruction repository | Centerline, parent/child, length, and diameter calculations with several experimental inconsistencies | **Archive / optional** | Preserve notes; do not treat current measurements as validated |
| `skeletonization_params.yaml` | Dawood reconstruction repository | Dormant-tree class and clustering parameters; includes implausible secondary voxel value | **Archive / optional** | Keep with original structural pipeline; do not apply to leafy cloud by default |
| `test.py` and example marker code | Dawood reconstruction repository | RViz line-strip example rather than a reconstruction test | **Exclude from current scope** | Retain only if useful as a tiny visualization example |
| `tfs.rviz` | Dawood reconstruction repository | Documents intended ROS 1 output topics and fixed frame | **Archive / reference** | Create a new RViz2 config for `/tree_scan/latest_tf_cloud` and `/tree_scan/global_cloud` |
| `ur5e.yml` | Dawood/lab cuRobo configuration | Robot model/config required for motion planning | **Active dependency** | Obtain authoritative file; verify joint names, kinematics, limits, and compatibility with current cuRobo version |
| `collision_table.yml` | Dawood/lab cuRobo configuration | Generic collision environment, not yet adequate for the Warthog-mounted arm | **Active dependency** | Replace or extend with the actual mount, camera, floor, equipment, and conservative specimen exclusion volume |
| Physical UR calibration | Lab/Universal Robots calibration process | Required for accurate live and replayed kinematics | **Active dependency** | Identify authoritative file and use consistently online/offline |
| Camera mount / hand–eye calibration | Lab hardware configuration | Required for reliable base-frame placement | **Active dependency** | Verify the complete fixed-frame-to-optical-frame chain; do not rely on ICP to compensate |
| Jetson camera driver and topics | Warthog Jetson | Publishes live ROS 2 RGB, aligned depth, and CameraInfo | **Active dependency** | Measure local/remote rates, encodings, QoS, timestamps, and frame IDs; record a bag |
| ROS 2 migrated reconstruction package | July 21 adaptation | New `ament_cmake`/Python package with ROS 2 motion, reconstruction, launch, parameters, safety, and output flow | **Active — adapt** | Clean-build and run reconstruction-only; then perform controller and supervised motion validation |
| `Spatio-Temporal-Mapping` | Nidhish GitHub repository | Clean baseline for the inherited Warthog orchard simulator | **Preserve — downstream** | Keep as simulator authority; avoid mixing reconstruction changes into it prematurely |
| Recovered `cornell_orchard_ws` | Lab desktop | Buildable ROS 2 simulator plus possible local uncommitted changes and artifacts | **Preserve — decision required** | Keep untouched recovery copy; retain selective patches separately; ask Nidhish before choosing variants |
| `.gitmodules` repair branch | David's repair based on recovered metadata | Restores the LIO-SAM source URL and makes recursive clones reproducible | **Preserve — decision required** | Ask Nidhish whether to merge by PR, retain unmerged, or remove |
| LIO-SAM upstream submodule | TixiaoShan/LIO-SAM at expected commit | Third-party mapping package used by the simulator | **Preserve — downstream** | Keep exact commit; use upstream attribution/license; no active reconstruction work needed |
| Project-specific LIO-SAM config/launch | Clean and recovered simulator copies | Differing local experiment settings | **Preserve — decision required** | Diff and document; defer selection until mapping work resumes |
| `orchard_description` worlds | Simulator repository and recovered workspace | Existing dormant/high-resolution orchard environments | **Preserve — downstream** | Replace absolute paths only when needed; later insert cleaned leafy assets |
| `generate_orchard_new_trees.py` variants | Clean and recovered `orchard_description` | Potentially different generations of orchard layout tooling | **Preserve — decision required** | Identify which version reflects the latest intended workflow before modifying |
| Orchard meshes/textures | Repository Git LFS and recovered workspace | Visual assets with incomplete per-file provenance | **Preserve — decision required** | Trace references and source/license before redistribution or derivative release |
| `orchard_final_high_res.sdf` variants | Clean and recovered `orchard_description` | Structural and path differences | **Preserve — downstream** | Defer portability cleanup until a reconstructed asset is ready for insertion |
| `orchard_perception` launch files | Clean and recovered workspaces | Simulator orchestration and mapping/perception integration | **Preserve — downstream** | Do not spend current time reconciling unless needed to demonstrate an imported tree |
| `temporal_projector.cpp` variants | Clean and recovered `orchard_perception` | Substantially different experimental implementations | **Preserve — decision required** | Keep both; obtain Nidhish's explanation before selecting or merging |
| Orchard RViz configs | Simulator repository and recovered workspace | Useful but non-authoritative visualization state | **Preserve — downstream** | Retain useful displays; low priority |
| `orchard_navigation_rl_ws` | Prior learned-navigation work | Behavior cloning, DAgger, policies, checkpoints, metrics, and evaluation separate from current assignment | **Exclude from current scope** | Archive and revisit only by explicit redirection |
| `final_colored_orchard.pcd` | Recovered desktop | Generated mapping/reconstruction result with incomplete run metadata | **Archive** | Store externally with any recoverable date, command, config, and data reference |
| `frames_*.gv` / `frames_*.pdf` | Recovered desktop | Generated TF diagrams | **Archive** | Keep under experiment artifacts; label with source workspace and date if known |
| `build-reproduction.log` | July 17 clean reproduction | Evidence that the inherited simulator built successfully | **Archive** | Attach to notes/issues or keep outside active source files |
| New scan bags, images, depth maps, PLY/PCD, JSON, CSV, and logs | Active experiments | Raw data and generated outputs from the migrated pipeline | **Archive as research data/artifacts** | Use a documented data hierarchy, checksums, metadata, and lab-approved storage—not normal Git history |

---

## Current Ownership Boundaries

### Active code owned by this adaptation effort

The current effort may claim authorship of the ROS 2 interface and engineering changes it actually introduces, including:

- ROS 2 package/build structure;
- `rclpy` node interfaces;
- ROS 2 action, TF2, QoS, synchronization, and `PointCloud2` integration;
- configurable camera/controller/frame parameters;
- the absolute raster generator;
- the move–settle–capture acknowledgement flow;
- motion-disable safety defaults;
- bounded ICP corrections;
- PLY and metadata output; and
- updated validation and operating documentation.

It should not claim original authorship of Dawood's reconstruction pipeline, Nidhish's simulator, upstream LIO-SAM, cuRobo, Open3D, Clearpath packages, or Universal Robots software.

---

## Rules for Using Inherited Work

1. Keep clean baselines and recovered snapshots separate.
2. Do not overwrite ambiguous competing versions.
3. Adapt only the components required for the current milestone.
4. Preserve attribution in file headers, commit messages, and documentation.
5. Treat unknown license or model-weight provenance as a release blocker, not as permission.
6. Keep generated data and logs outside normal source history unless an approved LFS/data policy exists.
7. Do not replace absolute paths globally just to make files look clean; fix them when the relevant workflow is understood and tested.
8. Do not execute inherited robot motion without validating the current hardware, controller, calibration, collision world, and start pose.
9. Prefer rosbags and offline replay so algorithm changes do not require repeated physical scans.
10. Record decisions from Dawood, Nidhish, and Divyanth in this register or linked issues.

---

## Required Maintainer Decisions

- Which repository should own the migrated reconstruction package?
- What branch/commit is the authoritative Dawood baseline?
- Should the `.gitmodules` repair be merged?
- Which `temporal_projector.cpp` version corresponds to which experiment?
- Which orchard generator and high-resolution world version should be retained?
- May the orchard meshes, textures, robot calibration, model weights, and collected tree data be redistributed?
- What is the expected minimum number and quality of reconstructed orchard trees?
- Who will supervise physical UR5e tests and orchard collection?

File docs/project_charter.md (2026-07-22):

# Cornell Warthog RGB-D Tree Reconstruction Pipeline

## Document Status

This is the active project charter as of July 21, 2026. It supersedes the earlier charter centered on building a general-purpose Warthog orchard-navigation simulation platform.

The earlier simulation work remains relevant as inherited infrastructure and as the eventual destination for reconstructed tree assets, but it is no longer the immediate project deliverable.

---

## Project Objective

Develop a reproducible ROS 2 Humble pipeline that adapts Dawood's inherited RGB-D tree-reconstruction workflow to the Cornell Warthog's UR5e-mounted camera, validates the pipeline on an indoor model tree, and produces reusable three-dimensional reconstructions of leafy orchard trees.

The immediate output is a metrically scaled colored point cloud, preserved with the raw data and metadata needed for repeatable offline processing. Mesh generation and Gazebo integration are downstream stages after the reconstruction itself is validated.

---

## Motivation

The inherited Gazebo orchard primarily represents dormant or winter trees. The laboratory needs real-tree-derived assets representing denser leafy canopies and current-season orchard conditions so that future perception and navigation systems can be evaluated under seasonal visual change.

Because David's remaining time at Cornell provides direct access to the physical Warthog, UR5e, RGB-D camera, indoor model tree, orchard, and lab personnel, hardware validation and raw data collection take priority over broad simulator cleanup.

---

## Active Technical Scope

The project will:

1. preserve the reusable acquisition and registration concepts from Dawood's ROS 1 code;
2. migrate the required nodes and package structure to ROS 2 Humble;
3. consume synchronized RGB, aligned depth, and camera intrinsics from the UR5e-mounted `camera_jetson` device;
4. obtain the camera pose from TF at the sensor timestamp;
5. create colored Open3D point clouds in a fixed robot frame;
6. use bounded coarse-to-fine ICP only as a refinement to valid TF-based placement;
7. coordinate arm movement through a move–settle–capture acknowledgement sequence;
8. save per-frame inputs, transforms, registration metrics, and fused PLY output;
9. validate the process first on a stationary frame, then on a small supervised indoor scan;
10. record raw RGB-D, TF, joint-state, and calibration data for offline replay;
11. collect several real leafy-tree datasets while physically at Cornell; and
12. prepare successful reconstructions for later cleaning, meshing, simplification, and Gazebo packaging.

---

## Intended System Architecture

```text
UR5e-mounted RGB-D camera
        ↓
ROS 2 camera driver on the Jetson
        ↓
RGB + aligned depth + CameraInfo
        ↓
TF2 lookup at the image timestamp
        ↓
Open3D colored point cloud in camera frame
        ↓
Transform into a fixed robot frame
        ↓
Bounded multiscale ICP refinement
        ↓
Filtering and global fusion
        ↓
PLY/PCD + per-frame metadata + ROS PointCloud2
        ↓
Offline cleanup and mesh generation
        ↓
Future Gazebo visual and collision assets
```

The motion side follows:

```text
verified UR5e joint state
        ↓
cuRobo plan to an absolute raster viewpoint
        ↓
ROS 2 FollowJointTrajectory execution
        ↓
settling delay
        ↓
capture request
        ↓
reconstruction acknowledgement
        ↓
next viewpoint
```

---

## Supported Environment

The active target environment is:

```text
Ubuntu 22.04 / Pop!_OS 22.04 base
ROS 2 Humble
Gazebo Fortress where simulation is used
Python 3.10
Open3D
cuRobo with CUDA-capable hardware for motion planning
Warthog + UR5e + Jetson/RealSense RGB-D camera
```

Primary camera inputs currently identified:

```text
/sensors/camera_jetson/color/image_raw
/sensors/camera_jetson/aligned_depth_to_color/image_raw
/sensors/camera_jetson/aligned_depth_to_color/camera_info
```

Supporting interfaces include TF, static TF, a verified UR5e joint-state source, and an active ROS 2 `FollowJointTrajectory` action server.

---

## Definition of Done

### Minimum deliverable for the Cornell visit

The minimum deliverable is complete when:

- the required reconstruction logic exists in a buildable ROS 2 package;
- one synchronized stationary RGB-D frame is converted into a correctly scaled and oriented PLY in the selected fixed frame;
- the live TF chain and camera intrinsics are verified;
- the final output and per-frame metadata are written without manual source edits;
- a short rosbag preserves the required RGB-D, TF, joint-state, and calibration inputs;
- one small supervised indoor model-tree scan completes through the move–settle–capture workflow;
- raw data from several real orchard trees is collected, subject to safe robot access and field conditions;
- at least two usable reconstructed tree point clouds are produced; and
- another researcher can reproduce the stationary-frame and offline-processing workflows from the documentation.

### Target deliverable

A stronger result includes:

- three to six successfully captured real trees;
- multiple accepted multi-view reconstructions;
- validated metric scale, orientation, and coordinate-frame conventions;
- preserved RGB, depth, CameraInfo, TF, ICP corrections, acceptance metrics, and parameter snapshots;
- a documented naming and data-retention convention;
- one cleaned reconstruction prepared for mesh generation; and
- one candidate visual asset and simplified collision representation prepared for later Gazebo insertion.

### Stretch deliverable

A stretch result includes:

- six to ten captured trees;
- multiple reconstructed models integrated into the inherited orchard world;
- an automated model/world-generation step; and
- an initial dormant-versus-leafy simulation experiment.

---

## Current State as of July 21, 2026

Completed or established:

- the inherited `cornell_orchard_ws` simulator was clean-built successfully under ROS 2 Humble;
- Gazebo Fortress loaded the orchard world and spawned the Warthog with controllers and simulated sensors;
- the GitHub `Spatio-Temporal-Mapping` repository was identified as the clean simulator baseline;
- the missing LIO-SAM submodule metadata was repaired on a separate branch and verified with a recursive clone;
- Git LFS assets were downloaded and compared with the recovered desktop workspace;
- the dedicated Linux laptop discovered and displayed the remote Warthog and Jetson camera streams;
- the remaining image issue was narrowed to low delivery rate and transport/QoS performance rather than discovery;
- Dawood's repository was separated into a reusable RGB-D reconstruction pipeline and a dormant-tree semantic/skeletonization pipeline;
- first-pass ROS 2 versions of the motion planner, point-cloud node, PointCloud2 helper, package files, parameters, and launch file were created;
- a default `execute_motion: false` interlock was added;
- an absolute raster and move–settle–capture handshake were designed; and
- the migrated Python code was syntax-checked.

Not yet demonstrated:

- a successful stationary PLY from the live UR5e-mounted camera;
- runtime compatibility with the actual trajectory controller;
- a verified six-joint UR5e joint-state topic;
- a validated fixed-frame-to-camera optical TF chain and hand–eye calibration;
- a complete indoor raster scan;
- physical arm motion using the migrated node;
- a real orchard-tree dataset; or
- a mesh or Gazebo-ready model.

---

## Immediate Milestones

### Milestone 1 — Stationary frame

```text
verify RGB and aligned-depth rates
→ inspect CameraInfo and frame IDs
→ verify TF at the image timestamp
→ trigger one capture with motion disabled
→ save PLY
→ inspect scale, orientation, color, and background
```

### Milestone 2 — Two-view validation

```text
capture first view
→ move once under supervision
→ settle
→ capture second view
→ compare TF-only and TF+ICP alignment
→ inspect fitness, RMSE, and duplicate surfaces
```

### Milestone 3 — Small indoor raster

Use a deliberately small, low-speed scan with a verified start pose, verified scan-plane axes, conservative collision geometry, and one acknowledged capture per viewpoint.

### Milestone 4 — Data preservation

Record a rosbag and save the parameter, calibration, TF, camera-info, environment, and output metadata needed to reproduce the scan offline.

### Milestone 5 — Orchard collection

Only after the indoor pipeline succeeds, schedule and perform supervised capture of several leafy trees while preserving raw data even if online reconstruction is incomplete.

---

## Primary Blockers and Required Validation

- identify the active UR5e `FollowJointTrajectory` action namespace;
- confirm that the selected joint-state topic contains all six arm joints;
- verify that camera, TF, controller, and Gazebo data use a consistent time source;
- verify the complete transform from the fixed robot frame through the UR5e and camera mount to the optical frame;
- obtain or confirm the physical robot calibration, `ur5e.yml`, `collision_table.yml`, and camera-mount calibration;
- compare camera publishing rate on the Jetson with the rate received on the laptop;
- configure Best Effort sensor QoS and compressed transport where appropriate;
- validate the collision model for the actual Warthog-mounted UR5e, camera housing, floor, nearby equipment, and specimen; and
- confirm supervision, field access, power, transport, weather, and operating permissions.

---

## Safety Constraints

- Physical motion remains disabled by default.
- No inherited hardcoded home pose or full scan path should be executed without validating the current robot configuration.
- The first motion test must use a small workspace, low speed, active supervision, and a known-safe start pose.
- ICP must not be used to conceal a missing or incorrect hand–eye calibration.
- The robot must stop and settle before each requested capture.
- Raw data must be recorded so that reconstruction tuning does not require repeating unsafe or expensive hardware motion.

---

## Deferred or Out-of-Scope Work

The following work is intentionally deferred unless the project is redirected:

- broad Gazebo portability cleanup;
- general Warthog navigation-platform development;
- Nav2 benchmarking;
- learned-policy integration or evaluation;
- LIO-SAM benchmarking;
- deep comparison of the two inherited `temporal_projector.cpp` variants;
- full cleanup of historical orchard worlds and assets;
- dormant-tree trunk/branch semantic segmentation;
- DBSCAN skeletonization and branch measurements;
- photorealistic or physically deformable foliage;
- support for multiple ROS distributions; and
- validated simulation-to-real equivalence.

These components should be preserved for future work but must not displace the immediate reconstruction and data-collection milestones.

---

## Expected Repository Deliverables

- ROS 2 package containing the migrated motion and reconstruction nodes;
- parameterized launch and configuration files;
- documented camera, controller, joint-state, TF, and time assumptions;
- stationary-frame and small-scan validation procedures;
- rosbag recording and offline-replay instructions;
- PLY/PCD and per-frame metadata outputs;
- sample results kept outside normal source-control history where large;
- provenance and inherited-work records;
- known-issues and future-work documentation; and
- downstream notes for cleaning, meshing, collision simplification, and Gazebo packaging.

---

## Future Research Direction

The larger research opportunity is not merely to scan trees. It is to create a reproducible, real-tree-derived, multi-season orchard simulation environment and use it to evaluate seasonal domain shift in agricultural perception and autonomous navigation.

Potential follow-on contributions include:

- reconstruction-quality evaluation;
- simulator integration;
- seasonal asset generation;
- dormant-versus-leafy experiments;
- multi-season training or domain randomization;
- perception and navigation robustness measurements;
- figures, ablations, and methods documentation; and
- publication writing.

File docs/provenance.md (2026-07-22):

# Provenance and Chain of Custody

## Purpose

This document records where inherited code, configuration, assets, and generated artifacts came from; what is currently known about authorship; what David changed; and which licensing or ownership questions remain unresolved.

An unknown license or author does not prove that an item is unusable, but it does mean the item should not be redistributed publicly or represented as original work until its status is verified.

---

## Source Authority Hierarchy

For the current project, use the following hierarchy unless a lab maintainer provides a newer authoritative source:

1. **Current active reconstruction package** — David's ROS 2 adaptation of the required portions of Dawood's pipeline.
2. **Dawood's reconstruction repository and handoff material** — source for the inherited RGB-D acquisition, registration, semantic segmentation, and skeletonization logic.
3. **`Spatio-Temporal-Mapping` GitHub repository** — clean baseline for Nidhish's Warthog orchard simulator.
4. **Recovered desktop `cornell_orchard_ws`** — recovery source for possible uncommitted simulator changes and generated outputs; not automatically authoritative over the clean repository.
5. **Upstream third-party repositories** — authoritative for their own code, licenses, and history, including the LIO-SAM submodule.
6. **`orchard_navigation_rl_ws`** — older, separate learned-navigation work; not an authority for the active reconstruction task.

---

## Chain of Custody

### Recovered lab-desktop workspaces

After receiving administrator access to the lab desktop, David located prior ROS workspaces while investigating the installed ROS and Gazebo environment. He copied the workspaces into his own directory for inspection and left the original directories untouched.

The recovered copy should therefore be treated as:

- a snapshot of files present on that machine;
- a possible source of uncommitted changes;
- a source of generated result artifacts; and
- evidence for comparison with the clean repository.

It should not be treated as proof of authorship, licensing, or final intended behavior without confirmation from Nidhish or another maintainer.

### Clean simulator repository

Nidhish identified `Spatio-Temporal-Mapping` as the clean repository baseline for the simulator. David initialized its dependencies, downloaded Git LFS content, and compared it with the recovered desktop workspace.

### Dawood reconstruction code

Dawood's code is the inherited basis for the tree-scanning and reconstruction workflow. The reviewed files include motion planning, point-cloud processing, semantic segmentation, skeletonization, tree-component analysis, utility code, launch files, and parameter files.

The active project adapts only the portions required for geometry-first RGB-D reconstruction. It does not imply authorship of Dawood's original algorithms.

---

## Provenance Register

| Item | Immediate source | Known or likely author | David's changes | Current role | License / release status |
| --- | --- | --- | --- | --- | --- |
| `Spatio-Temporal-Mapping` repository | Nidhish's GitHub repository | Nidhish and prior Cornell contributors; exact per-file authors in Git history | Comparison, setup repair branch, reproduction notes | Clean simulator baseline | Verify repository license and per-asset exceptions before public release |
| Recovered `cornell_orchard_ws` | Lab desktop user directories | Nidhish / other prior lab contributors; exact authors vary | Copied for inspection; originals left untouched; no blanket merge | Recovery source for local changes and artifacts | Internal status and per-file licensing require verification |
| `src/LIO-SAM` | Git submodule pointing to `https://github.com/TixiaoShan/LIO-SAM.git` | Upstream LIO-SAM authors | Restored missing `.gitmodules` metadata; preserved expected commit `08af3f32f01725372d4269838dc44c19c6d9e76b` | Third-party mapping dependency in simulator | Use upstream repository/license; do not describe upstream code as Cornell-authored |
| LIO-SAM project configuration | Clean and recovered simulator workspaces | Likely Nidhish/project contributors, based on upstream package | No authoritative merge selected; differences preserved | Deferred simulator-specific configuration | Attribution follows Git history; verify before publishing configuration as a lab release |
| `orchard_description` worlds and generators | Clean and recovered simulator workspaces | Nidhish / Cornell contributors; some assets may have other origins | Reproduction and comparison only so far | Downstream environment and asset integration | Per-mesh, texture, and imported-model provenance remains incomplete |
| Orchard meshes and textures tracked through Git LFS | `orchard_description` / repository LFS | Unknown at present | Downloaded LFS objects for comparison; no claim of authorship | Simulator visual assets | Do not redistribute externally until source and license are documented |
| `orchard_perception` code | Clean and recovered simulator workspaces | Nidhish / Cornell contributors | Compared major files; no implementation selected | Deferred simulator perception/mapping | Check Git history and repository license |
| Competing `temporal_projector.cpp` versions | Clean repository and recovered workspace | Nidhish / prior lab experimentation | Preserved both; no merge | Deferred experimental variants | Ownership likely Cornell-internal; confirm purpose and release status with Nidhish |
| `orchard_navigation_rl_ws` | Recovered or existing learned-navigation repository/workspace | Nidhish, Divyanth, and/or prior contributors | None beyond review and scope classification | Archived separate work | Check its own repository, dependencies, checkpoints, and dataset licenses |
| Dawood `motion_planner.py` | Dawood reconstruction repository | Dawood plus third-party cuRobo/ROS concepts | Rewritten to ROS 2 API; name-based joints; configurable action; absolute raster; safety interlock; capture handshake | Active inherited logic under adaptation | Preserve attribution to Dawood; verify original repository license and third-party notices |
| Dawood `pointcloud_processing.py` | Dawood reconstruction repository | Dawood plus Open3D/ROS concepts | Rewritten to ROS 2; geometry-first mode; TF2; topic/encoding/depth handling; bounded ICP; outputs and metadata | Active inherited logic under adaptation | Preserve attribution to Dawood; verify original repository license |
| Dawood `pc_utils.py` | Dawood reconstruction repository | Dawood | Replaced ROS 1 `ros_numpy` conversion with direct ROS 2 `PointCloud2` helper; consolidation still possible | Active utility layer | Preserve original attribution for retained logic |
| Dawood YOLO/BiSeNet integration and model weights | Dawood repository and external model files | Dawood integration; model/framework authors external | Bypassed for initial leafy reconstruction | Optional/deferred | Model-weight and dataset licenses must be checked separately from code |
| Dawood skeletonization and `tree_component.py` | Dawood repository | Dawood | Reviewed; not migrated into the initial geometry-first path | Archived / optional later | Preserve attribution; verify repository license before reuse or publication |
| ROS 2 migration package | Created from July 21 adaptation work | David for migration/refactor; inherited algorithms remain attributed to Dawood and external projects | New package/build/launch/parameter structure and ROS 2 interface layer | Active current code | Add a clear NOTICE/attribution file before release; choose license with lab approval |
| Clearpath Warthog simulation stack | Installed ROS 2 packages and generated Clearpath configuration | Clearpath Robotics and package contributors | Reproduction, setup-path diagnosis, and configuration use | Simulator dependency | Follow upstream package licenses and model terms |
| Universal Robots ROS 2 driver/calibration | Installed or lab-provided UR software and calibration | Universal Robots ROS driver contributors; lab calibration generated for the physical arm | Integration pending | Physical motion dependency | Do not publish robot-specific calibration without lab approval |
| cuRobo | External motion-planning framework and config files | Upstream cuRobo authors; local configs may be Dawood/lab-authored | Interface adaptation and safety checks | Motion-planning dependency | Follow upstream license; determine provenance of `ur5e.yml` and `collision_table.yml` |
| Open3D | External library | Open3D authors | Used for RGB-D back-projection, registration, filtering, and PLY output | Reconstruction dependency | Follow upstream license |
| `final_colored_orchard.pcd` | Recovered desktop workspace | Generated by an earlier experiment; operator/config unknown | None | Archived result artifact | Not source code; document generating command/data before reuse in a publication |
| `frames_*.gv` / `frames_*.pdf` | Recovered desktop workspace | Generated by TF visualization tooling | None | Archived diagnostic artifacts | Tool-generated; accompanying robot/config provenance remains necessary |
| `build-reproduction.log` | David's clean-build reproduction | David as operator; content from build tools and packages | Generated during reproduction | Diagnostic evidence | Keep out of source unless attached to an issue or handoff record |
| New PLY/PCD, images, depth frames, bags, metrics, and summaries | Active reconstruction runs | David/lab operators as data collectors; subjects and hardware lab-owned | Generated by the adapted pipeline | Research data and experiment artifacts | Store under lab-approved data policy; record date, operator, hardware, parameters, and consent/access restrictions |

---

## Third-Party and External Dependency Notes

The active repository should distinguish source code written or modified by the project from external dependencies installed through ROS, Python, CUDA, or system package managers.

At minimum, preserve attribution and verify licensing for:

- LIO-SAM;
- Clearpath ROS 2 / Gazebo packages and models;
- Universal Robots ROS 2 driver and calibration tools;
- cuRobo;
- Open3D;
- ROS 2, TF2, message_filters, and related packages;
- YOLO/Ultralytics if retained;
- BiSeNet and any copied `lib/` code if retained;
- model weights and their training datasets;
- imported Gazebo meshes, textures, and SDF/URDF assets; and
- any code generated or substantially assisted by automated tools.

Dependency names in package manifests do not require copying their source into this repository. Vendored or modified third-party code requires clearer notices and, where applicable, preservation of license files.

---

## Authorship and Modification Rules

When documenting or publishing the project:

- attribute the original reconstruction workflow and project-specific ROS 1 code to Dawood unless Git history establishes more specific authorship;
- attribute the ROS 2 migration, interface refactor, safety interlocks, and new output workflow to David while making clear that the underlying reconstruction concepts were inherited;
- attribute simulator components according to their Git history and Nidhish's handoff;
- attribute LIO-SAM and other external libraries to their upstream authors;
- do not call recovered local files “David's code” merely because David copied or repaired them;
- do not call generated point clouds, TF diagrams, logs, or meshes source code; and
- do not infer a license from a neighboring package or parent repository when an asset may have been imported separately.

---

## Data and Artifact Metadata

Every new scan dataset or reconstruction should record, at minimum:

```text
date and time
operator
location and tree identifier
indoor/outdoor condition
robot and camera identifiers
ROS distribution and package commit
camera topics and frame IDs
fixed reconstruction frame
camera intrinsics
hand–eye / mount calibration reference
UR calibration reference
controller and joint-state interfaces
parameter snapshot
raw rosbag path and checksum
accepted/rejected frame counts
PLY/PCD path and checksum
notes on motion, lighting, wind, occlusion, and failures
```

Large data should not be committed directly to normal Git history unless the repository intentionally uses Git LFS and the lab approves the storage policy.

---

## Open Provenance Questions

1. What is the exact repository URL, branch, and commit for Dawood's latest reconstruction code?
2. What license, if any, applies to Dawood's project-specific files?
3. Who created each orchard mesh, texture, and tree model, and were any imported from external sources?
4. What license governs the clean `Spatio-Temporal-Mapping` repository?
5. Which recovered simulator files are uncommitted work by Nidhish, and which are generated or copied artifacts?
6. What experiments produced the two `temporal_projector.cpp` variants?
7. What command, dataset, and configuration produced `final_colored_orchard.pcd`?
8. What are the authoritative `ur5e.yml`, `collision_table.yml`, physical UR calibration, and camera-mount calibration sources?
9. Who owns and may redistribute the YOLO/BiSeNet weights and training data?
10. What lab policy governs release of robot calibration, orchard data, imagery, and reconstructed tree assets?
11. Which repository should ultimately own the migrated ROS 2 reconstruction package?
12. What acknowledgements or contributor credits do Divyanth, Dawood, Nidhish, and the lab expect in a future release or paper?

---

## Release Checklist

Before a public repository, paper supplement, or external asset release:

- verify the license at the repository root;
- add NOTICE/ATTRIBUTION documentation;
- preserve upstream license files for vendored code;
- confirm per-asset provenance for meshes, textures, weights, and data;
- remove credentials, private paths, hostnames, and personal identifiers;
- review robot-specific calibration and internal network details with the lab;
- confirm that Cornell permits release of collected orchard imagery and reconstructions;
- separate source from large generated data and experiment outputs; and
- tag the exact commits and parameter snapshots used for reported results.

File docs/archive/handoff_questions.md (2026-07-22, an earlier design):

# Better questions for Nidhish 
1. Which of the two workspaces is authoritative? (cornell_orchard_ws & orchard_navigation_rl_ws)
1. Are they intended to be launched together?
1. What exact command produced the latest successful Gazebo run?
1. Which files contain local changes that were never committed?
1. Was Gazebo Fortress, Classic, Garden, or Harmonic used? (conflicting versions)
1. Which orchard world is the final one?
1. Were the policies ever run closed-loop in simulation?
1. Were the current metrics calculated on individual frames or complete held-out trajectories?
1. How were training, validation, and test data separated?
1. Why does fusion help angular prediction but hurt linear prediction?
1. Why do the multimodal and camera models never predict stop?
1. What is the intended safety behavior when the model fails?
1. What should your three-week contribution own: simulation reproduction, closed-loop evaluation, Nav2 baseline, or all three?

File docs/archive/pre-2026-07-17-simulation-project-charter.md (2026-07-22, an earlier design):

# Archived Pre-Pivot Project Charter

> **Archived scope record — not active requirements.**  
> This document preserves the simulation/navigation-centered charter that existed before the July 17, 2026 project pivot. It is superseded by `project_charter.md`, which makes RGB-D tree reconstruction, ROS 2 migration, indoor validation, and orchard data collection the active priorities.

---

# Cornell Warthog Orchard Simulation Platform

## Project Objective

Extend the Cornell AgRobotics Lab’s existing simulation work into a reproducible Gazebo-based apple-orchard environment in which a simulated Clearpath Warthog can be launched, operated, mapped, and used for initial testing of autonomous-navigation algorithms before field deployment.

The project will build on the previous intern’s work rather than begin from scratch.

## Motivation

The lab currently needs to transport the physical Warthog to an orchard to test navigation algorithms and software changes. Field testing is time-consuming, and even a small software failure may require returning the robot to the lab, correcting the problem, and repeating the deployment.

A reusable simulation platform would provide an initial validation stage for detecting integration problems and evaluating navigation behavior before using the physical robot. Divyanth identified this as potentially useful across multiple lab projects and as a contribution that could support future publication work.

## Narrow Scope for the Cornell Visit

The initial scope is not to create a perfectly photorealistic digital twin of an orchard or solve every aspect of autonomous navigation.

The goal is to produce one functioning, reproducible end-to-end simulation workflow:

1. Launch the selected Gazebo orchard world.
2. Spawn the appropriate Warthog model and sensor configuration.
3. control or navigate the Warthog through orchard rows.
4. Produce or load a map using the lab’s selected mapping approach.
5. Run at least one representative navigation or planning workflow.
6. Record whether the workflow succeeds and where it fails.
7. Document installation, launch, configuration, and known limitations.

## Definition of Done

The initial project is complete when a new lab member can follow the repository documentation on the supported Linux environment and reproduce the following workflow without undocumented manual intervention:

* Build or install all required dependencies.
* Launch Gazebo with an apple-orchard world containing navigable rows.
* Spawn the Warthog with the agreed-upon sensor configuration.
* Confirm that required ROS topics, transforms, and simulated sensor outputs are available.
* Drive the robot manually through at least one orchard row.
* Generate or use a map of the environment.
* launch one agreed-upon navigation stack or planning algorithm.
* Send the Warthog to one or more goals without colliding with static orchard geometry.
* Save logs, maps, configuration files, and representative results.
* Reproduce the workflow using a documented launch command or small set of commands.

Completion does not require the simulated system to match real-world orchard performance perfectly. Simulation-to-reality validation is a later research stage.

## Expected Deliverables

* Reproducible ROS/Gazebo workspace.
* Version-controlled orchard world and configuration files.
* Warthog model integration.
* Documented simulated sensor configuration.
* Launch files for the end-to-end workflow.
* Mapping and navigation configuration.
* Basic validation procedure and results.
* README containing installation and execution instructions.
* Known-issues and future-work document.
* Architecture or system diagram.
* Short demonstration video or screen recording, if feasible.

## Current Blockers

### Immediate blockers

* The previous intern’s repository has not yet been transferred.
* The project’s existing Ubuntu, ROS, and Gazebo versions are unknown.
* The current completion state of the previous intern’s mapping work is unknown.
* Access to an appropriate Linux workstation or laptop has not yet been confirmed.

### Technical unknowns

* Exact Warthog model and package used by the previous intern.
* Physical Warthog sensor configuration that should be reproduced.
* Whether the lab uses ROS 1 or ROS 2.
* Whether the repository uses Gazebo Classic or modern Gazebo.
* Existing orchard-world source and licensing.
* Mapping package previously attempted.
* Navigation stack and planner that the lab wants to evaluate.
* Existing errors in launch files, transforms, sensor topics, or configuration.
* Required computing and GPU resources.
* Preferred destination and ownership of the maintained repository.

## Assumptions to Validate

* A usable open-source Warthog simulation model exists.
* The previous intern created a recoverable Git repository.
* Some orchard environment or reusable orchard assets already exist.
* The unfinished work is sufficiently complete to provide a starting point.
* The lab’s primary short-term need is navigation and mapping rather than photorealistic perception.
* The physical Warthog’s relevant sensors can be represented in Gazebo.
* A supported Linux machine can be provided or configured.
* The project can continue after July 30 if full evaluation is not completed during the visit.

## Explicit Non-Goals for the Initial Three Weeks

Unless Divyanth changes the scope, this phase will not attempt to:

* Construct an exact digital twin of a specific Cornell orchard.
* Develop a new SLAM or path-planning algorithm from first principles.
* Model all vegetation physics or seasonal variation.
* Achieve validated simulation-to-real performance equivalence.
* Build an entire perception system unrelated to navigation.
* Replace the lab’s existing robotics software architecture.
* Support several ROS and Gazebo versions simultaneously.

## Immediate Actions

1. Obtain the previous intern’s repository and technical handoff.
2. Request the exact Ubuntu, ROS, Gazebo, and package versions.
3. Secure a suitable Linux machine.
4. Obtain the physical Warthog and sensor specifications.
5. Determine the preferred repository destination and maintainers.
6. Run the existing project unchanged before modifying it.
7. Convert all discovered failures into tracked GitHub issues.
8. Agree with Divyanth on one minimum end-to-end demonstration.
9. Establish one measurable navigation evaluation beyond merely showing that the simulator launches.

## Questions for the Handoff Meeting

* What operating system, ROS distribution, and Gazebo version does the repository require?
* Is this Gazebo Classic, Ignition Gazebo, or modern Gazebo?
* Which branch or commit represents the latest working state?
* What currently launches successfully?
* What was the last end-to-end workflow that worked?
* What part of mapping remains unfinished?
* Which errors or limitations were already known?
* Which Warthog model and sensor plugins are used?
* Does the simulated sensor suite match the physical Cornell Warthog?
* What orchard assets were used, and where did they come from?
* Which SLAM and navigation packages were attempted?
* Are there recorded commands, maps, bags, videos, or experiment notes?
* What would the former intern have implemented next?
* What hardware was used to run the simulation?
* Are there uncommitted files or local configuration changes?
* What licenses apply to the model, world, and imported assets?

## Success Beyond the Minimum

A stronger research contribution would add a repeatable evaluation layer rather than only producing a working simulation. This could include predefined routes, automated trial execution, collision and completion metrics, localization error where ground truth is available, path length, traversal time, intervention count, and controlled variations in orchard geometry or sensor noise.

That evaluation layer would make the platform more useful for comparing future algorithms and more defensible as a publication contribution.

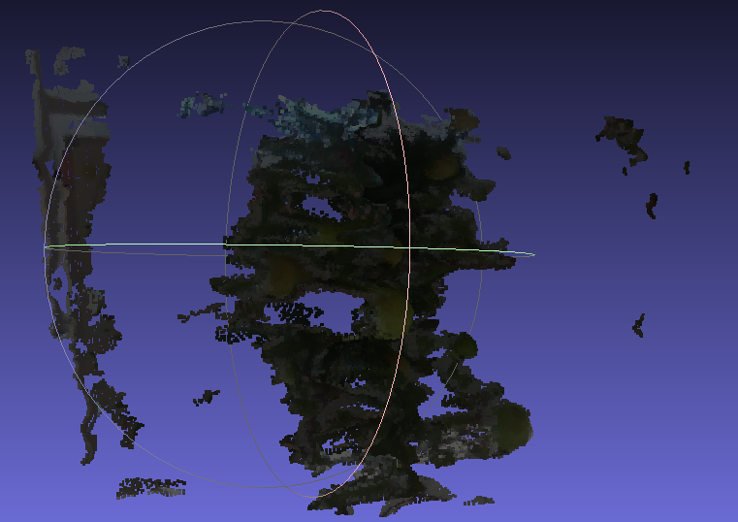
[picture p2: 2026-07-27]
docs/progress_pics/Screenshot from 2026-07-23 17-18-08.png

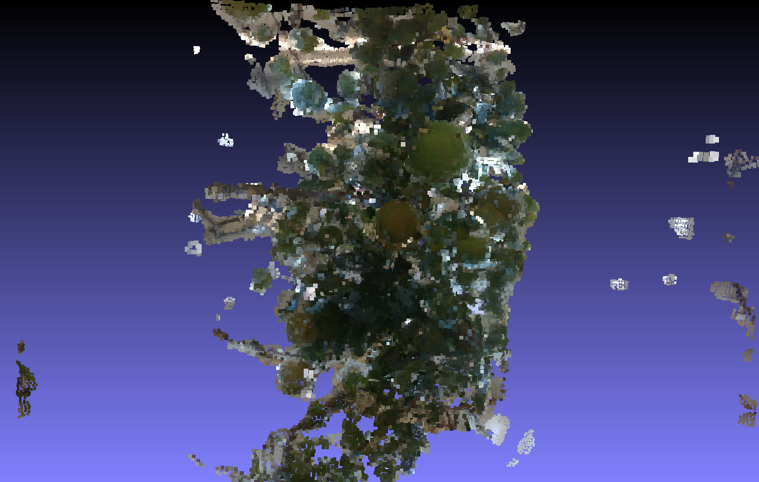
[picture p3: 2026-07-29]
docs/progress_pics/indoor_model_tree_100.png

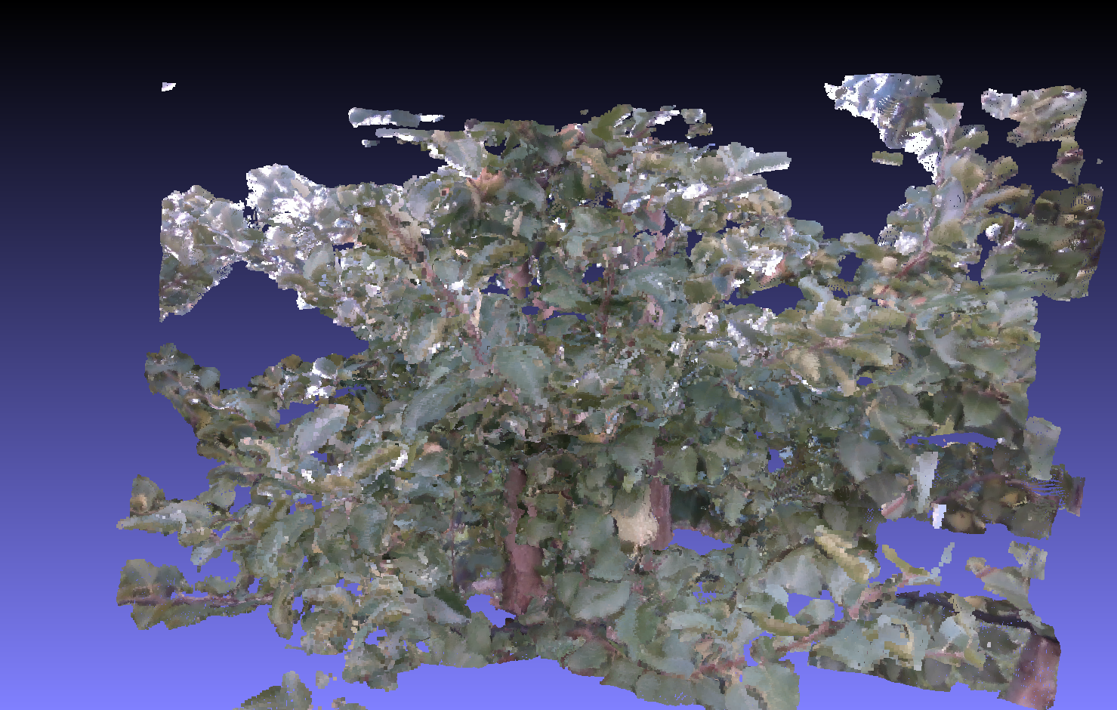
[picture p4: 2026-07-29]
docs/progress_pics/outdoor_tree_300.png

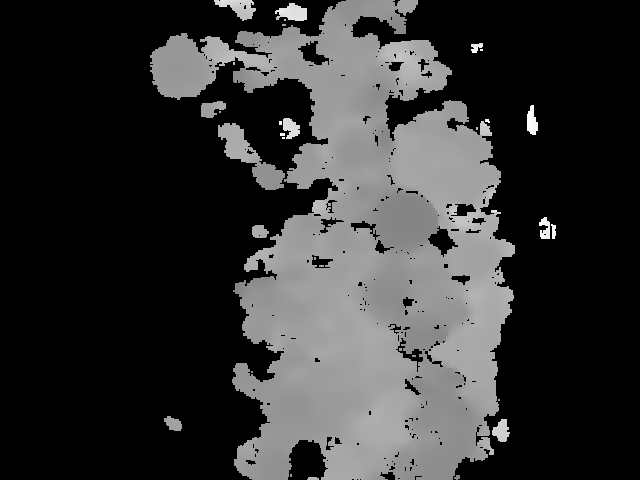
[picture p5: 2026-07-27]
docs/progress_pics/0000_depth.png

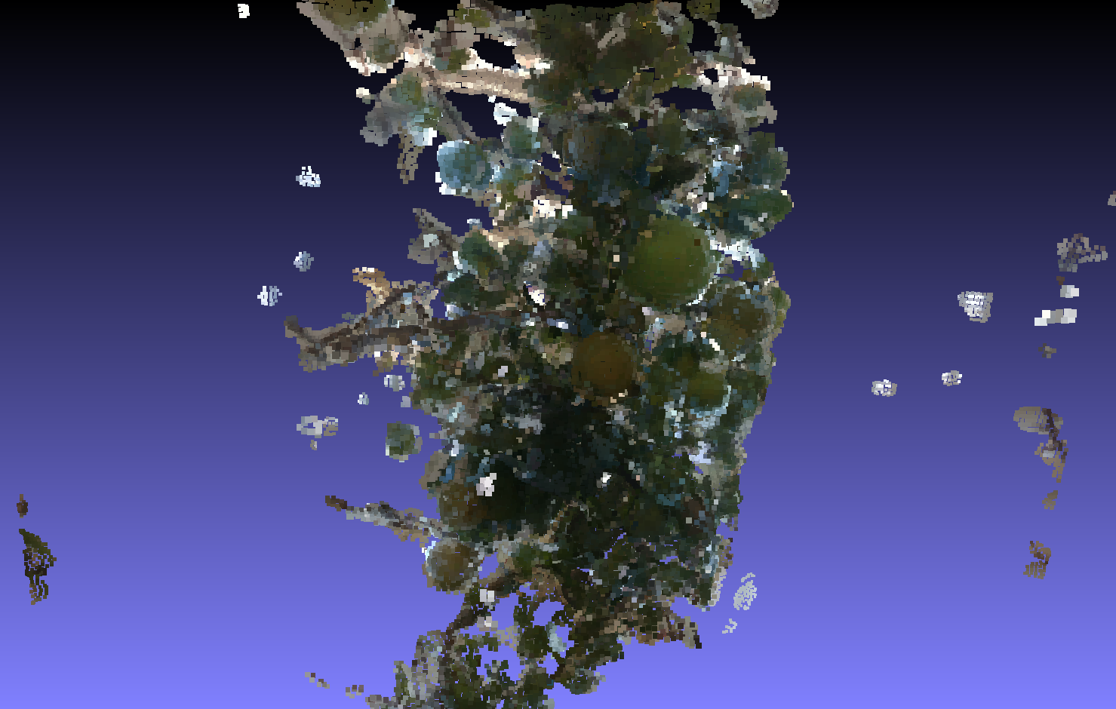
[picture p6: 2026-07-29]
docs/progress_pics/indoor_model_tree_200.png

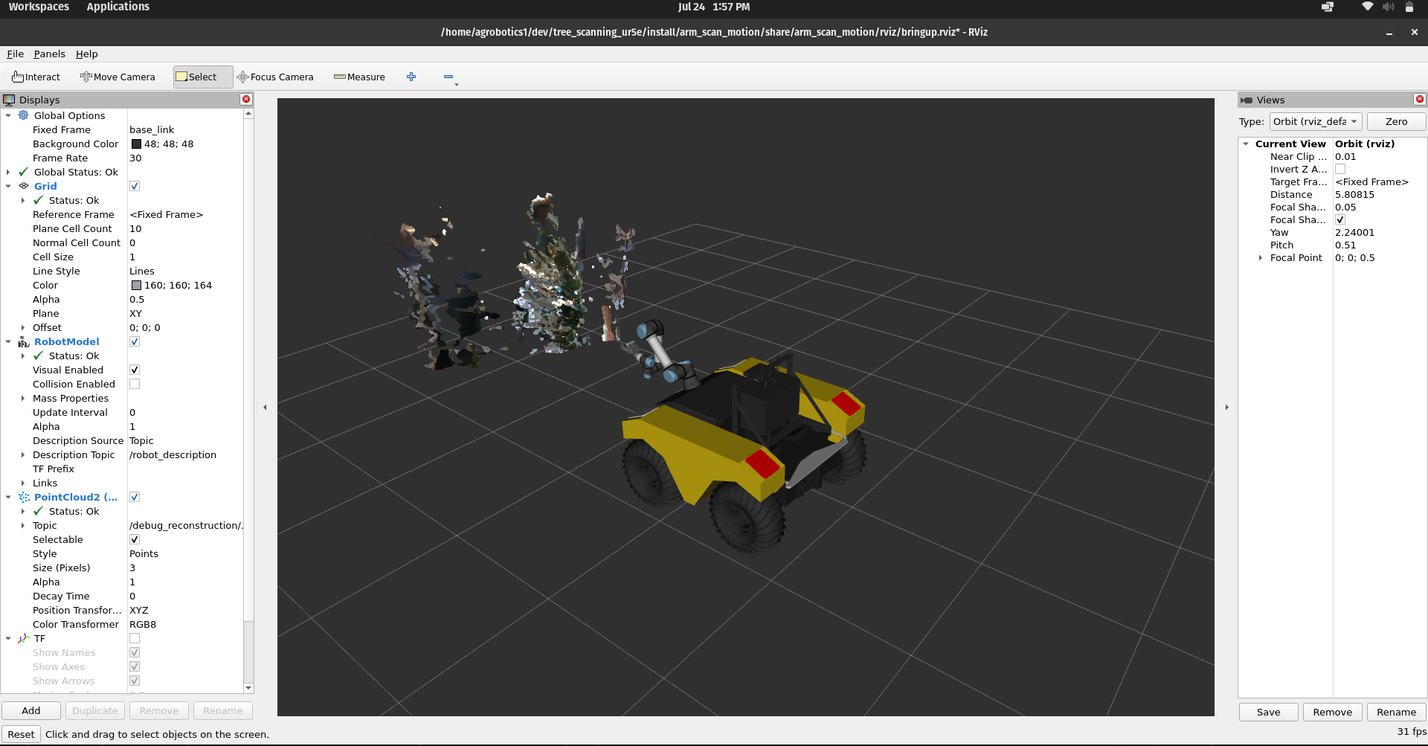
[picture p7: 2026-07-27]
docs/progress_pics/Screenshot from 2026-07-24 13-57-24.png

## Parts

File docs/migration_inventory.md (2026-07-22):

# Migration and Repository Inventory

## Purpose

This document tracks two related but distinct efforts:

1. the active migration of Dawood's ROS 1 tree-scanning and reconstruction workflow to ROS 2 Humble; and
2. the disposition of differences found between the clean inherited simulator repository and the recovered desktop workspaces.

Status terms:

- **Implemented — unvalidated:** code exists and parses, but has not been proven against the live system.
- **Pending:** required work or verification remains.
- **Deferred:** preserve for later; not part of the immediate reconstruction milestone.
- **Archive:** keep as evidence or output, but do not treat as active source.
- **Exclude:** do not import into the active codebase unless the scope changes.

---

## A. Active ROS 1 → ROS 2 Humble Migration

| Area | Inherited state | Current action | Status | Required validation |
| --- | --- | --- | --- | --- |
| Package build system | ROS 1 catkin package | Convert to `ament_cmake` + `ament_cmake_python`; install Python executables, launch, and config | Implemented — unvalidated | Clean `colcon build` in the target workspace |
| Node API | `rospy` | Replace with `rclpy.node.Node` | Implemented — unvalidated | Start both nodes and inspect parameters/logging |
| Parameters | ROS 1 global parameter server and hardcoded values | Use node-scoped ROS 2 YAML parameters | Implemented — unvalidated | Confirm launch-time overrides and parameter types |
| Trajectory action | `actionlib.SimpleActionClient` | Use ROS 2 `rclpy.action.ActionClient` and configurable action name | Implemented — unvalidated | Identify and connect to the actual active action server |
| Controller handling | Old controller names and ROS 1 controller-manager calls | Do not switch controllers automatically; require an already active controller | Implemented — unvalidated | Run `ros2 control list_controllers` and verify namespace |
| Joint-state ordering | Positional assumptions and manual swapping | Map positions by joint name into cuRobo/controller order | Implemented — unvalidated | Confirm the selected topic includes all six UR5e joints |
| cuRobo tensors | GPU tensors passed toward ROS messages | Convert trajectory values to CPU Python lists | Implemented — unvalidated | Plan a trajectory without executing motion |
| CUDA dependency | Hardcoded `cuda:0` assumption | Check CUDA availability before cuRobo initialization | Implemented — unvalidated | Test on the actual laptop/workstation GPU |
| Quaternion handling | ROS and cuRobo conventions mixed implicitly | Treat cuRobo as `wxyz`; ROS transforms as `xyzw`; normalize where required | Implemented — unvalidated | Verify a known orientation and scan-plane direction |
| Scan path | Long accumulated relative-motion sequence | Generate a parameterized absolute snake/raster around the verified start pose | Implemented — unvalidated | Visualize or dry-run all waypoints before motion |
| Home behavior | Hardcoded joint pose | Optional return to recorded scan-start pose | Implemented — unvalidated | Confirm controller acceptance and safe workspace |
| Motion safety | Main code could run the wrong mode | Default `execute_motion: false`; require explicit enablement | Implemented — unvalidated | Confirm launch default on the target system |
| Capture coordination | Continuous processing; incomplete alert publisher | Add move–settle–capture request and `/capture_done` acknowledgement | Implemented — unvalidated | Trigger several manual captures without arm motion |
| Camera topics | ROS 1 Azure Kinect topic names | Parameterize and default to `camera_jetson` ROS 2 topics | Implemented — unvalidated | Verify frequency, QoS, encodings, and frame IDs |
| Camera synchronization | ROS 1 message filters with 1 ms slop | ROS 2 `message_filters` with sensor-data QoS and configurable tolerance | Implemented — unvalidated | Measure real timestamp offsets and accepted callback rate |
| Image encodings | BGRA and `16UC1` assumed | Support common RGB/BGR/RGBA/grayscale encodings and `16UC1`/`32FC1` depth | Implemented — unvalidated | Capture representative messages from the live camera |
| Depth units and limits | Hardcoded values; incorrect 1 m/2 m comment | Infer depth scale by encoding; parameterize minimum/maximum depth | Implemented — unvalidated | Inspect reconstructed metric scale and clipping |
| Camera intrinsics | ROS 1 CameraInfo | Read aligned-depth-to-color CameraInfo in ROS 2 | Implemented — unvalidated | Confirm `K`, width, height, and matching image dimensions |
| TF | ROS 1 `tf.TransformListener` and hardcoded frames | Use `tf2_ros.Buffer`/`TransformListener`; read camera frame from headers | Implemented — unvalidated | Verify fixed-frame-to-optical-frame transform at capture timestamps |
| Point-cloud generation | Open3D RGB-D back-projection | Retain geometry-first colored reconstruction; correct BGR/RGB ordering | Implemented — unvalidated | Produce one stationary colored PLY |
| ROS cloud publishing | `ros_numpy` / ROS 1 helper | Construct ROS 2 `PointCloud2` directly with packed RGB | Implemented — unvalidated | View latest and global clouds in RViz2 |
| Semantic segmentation | YOLO/BiSeNet trunk/branch masks; black geometry discarded | Bypass for initial leafy-tree reconstruction | Implemented by omission | Confirm full foliage/background geometry is retained |
| ICP | Global multiscale point-to-plane ICP | Retain as bounded correction with configurable thresholds and local target crop | Implemented — unvalidated | Compare TF-only vs. TF+ICP on two controlled views |
| ICP safety limits | No explicit correction bound | Reject implausible translation/rotation corrections | Implemented — unvalidated | Log and inspect corrections across controlled captures |
| Filtering | Hardcoded voxel/radius values | Parameterize local/global voxel and radius-outlier settings | Implemented — unvalidated | Tune without deleting small leaves and twigs |
| Capture state | Continuous automatic re-enable | Queue exactly one synchronized frame per request; retain pending request on temporary TF failure | Implemented — unvalidated | Repeated manual trigger test |
| Output | Published cloud only; no persistent final model | Save fused PLY after each capture plus per-frame RGB/depth/intrinsics/TF/ICP/metrics | Implemented — unvalidated | Verify unique paths, file integrity, and metadata consistency |
| Live timeout | Eight-second watchdog suitable only for bag replay | Remove unsafe live idle shutdown | Implemented — unvalidated | Leave node idle between manual captures |
| Launch | ROS 1 launch files and Dawood-specific paths | Add ROS 2 Python launch file and configurable output path | Implemented — unvalidated | Launch reconstruction-only with motion disabled |
| Time source | ROS 1/live assumptions | Parameterize `use_sim_time`; require consistent camera, TF, and controller clocks | Pending | Confirm `/clock` bridge in Gazebo and wall time on hardware |
| Rosbag | ROS 1 `rosbag record/play` launch | Design ROS 2 `ros2 bag` recording and replay workflow | Pending | Record and replay all required topics |
| Calibration/config | Physical UR calibration, camera mount, `ur5e.yml`, and `collision_table.yml` external or missing | Obtain and verify authoritative files | Pending | Validate against the actual Warthog-mounted UR5e |
| Dependencies | ROS 1 packages plus YOLO/BiSeNet remnants | Declare ROS 2 runtime dependencies; isolate optional semantic stack | Pending | Fresh-machine installation test |

---

## B. Clean Simulator Repository vs. Recovered Desktop Workspace

| Difference or artifact | Current interpretation | Disposition | Priority / next action |
| --- | --- | --- | --- |
| `.gitmodules` missing for `src/LIO-SAM` | Repository tracked a submodule commit but lacked its source URL | Keep the repair branch; do not silently merge | Ask Nidhish whether he wants a PR, retained branch, or removal |
| `src/LIO-SAM` commit | Expected commit is `08af3f32f01725372d4269838dc44c19c6d9e76b` from TixiaoShan/LIO-SAM | Preserve exact pointer | Reverify during a clean recursive clone |
| Git LFS pointer files | Orchard geometry appeared as ~130-byte pointer files until `git lfs pull` | Keep LFS tracking; do not duplicate binaries outside the intended storage model | Document Git LFS as a setup requirement |
| LIO-SAM `config/params.yaml` | Project-specific configuration differs between clean and recovered copies | Preserve both versions and diff | Deferred unless reconstruction or later mapping depends on it |
| LIO-SAM `launch/run.launch.py` | Recovered launch changes may include machine/project-specific behavior | Preserve patch; do not choose a winner without context | Deferred |
| LIO-SAM `config/rviz2.rviz` | Visualization-only differences | Retain useful display settings if later needed | Low priority |
| `orchard_description/scripts/generate_orchard_new_trees.py` | Competing generator versions may encode later local work | Preserve both and identify authoritative/latest intent | Downstream priority for seasonal asset integration |
| `orchard_description/worlds/orchard_final_high_res.sdf` | Includes structural and absolute-path differences | Preserve; replace home paths only when simulator integration resumes | Deferred |
| `orchard_perception/launch/infrastructure.launch.py` | Recovered orchestration differs from clean baseline | Preserve patch | Deferred |
| `orchard_perception/launch/main_launcher.py` | Recovered orchestration differs from clean baseline | Preserve patch | Deferred |
| `orchard_perception/rviz/orchard_mapping.rviz` | Low-risk visualization differences | Retain externally or as a documented patch | Low priority |
| `orchard_perception/src/temporal_projector.cpp` | Two substantially different experimental implementations | Preserve both; do not merge or overwrite | Ask Nidhish which experiment each version represents |
| Absolute `/home/divyanth`, `/home/nidhish`, and `/home/nidhish27` paths | Machine-specific portability defects | Replace with package share paths, `model://`, resource paths, and launch arguments only when touched | Deferred except where they block a required run |
| `/etc/clearpath` generated files | Root-owned setup path causes permission failures; old generated files can mask the issue | Use a user-writable `setup_path`; never launch ROS/Gazebo with `sudo` | Document for future simulator reproduction |
| `final_colored_orchard.pcd` | Experimental result, not source | Archive outside normal source tree or under a results store | Preserve with context and generation metadata if recoverable |
| `frames_*.gv` and `frames_*.pdf` | Generated TF diagrams | Archive under experiment artifacts/docs | Preserve; do not treat as authoritative without date/config |
| `build-reproduction.log` | Locally generated reproduction evidence | Archive or attach to an issue; do not maintain as source | Keep only if useful for handoff |
| `meshes/` | Actual use and authorship not fully known | Preserve; do not redistribute externally until provenance is verified | Inspect references and licenses before release |
| `urdf/` | May contain dormant or machine-specific material | Preserve | Low priority unless required by current TF/controller setup |
| `orchard_navigation_rl_ws` | Earlier behavior-cloning/learned-navigation work, separate from current authoritative workspace | Archive and exclude from active reconstruction work | Revisit only if Divyanth redirects the project |

---

## C. Component Disposition for the Current Project

| Component | Disposition | Reason |
| --- | --- | --- |
| Dawood RGB-D acquisition and Open3D reconstruction concepts | **Adapt** | Core of the active deliverable |
| Dawood ROS 1 interfaces | **Replace** | Incompatible with ROS 2 Humble system |
| Dawood YOLO/BiSeNet semantic coloring | **Defer** | Specialized for dormant trunk/branch analysis and likely removes foliage |
| Dawood skeletonization and branch measurement | **Archive / optional later** | Not required for a geometry-first leafy reconstruction |
| ROS 2 migrated motion/reconstruction package | **Active** | Current implementation layer; runtime validation pending |
| Clean `Spatio-Temporal-Mapping` repository | **Preserve as baseline** | Authoritative simulator baseline identified during handoff |
| Recovered `cornell_orchard_ws` | **Preserve as recovery source** | May contain uncommitted experimental changes; originals should remain untouched |
| Orchard worlds, meshes, and generators | **Preserve for downstream integration** | Eventual destination for reconstructed assets |
| LIO-SAM and mapping configuration | **Defer** | Not required for the stationary-frame or small indoor reconstruction milestones |
| Learned navigation stack | **Exclude from current scope** | Separate prior work with no immediate dependency |
| Generated PCD/PLY, bags, images, logs, and TF diagrams | **Store as artifacts/data** | Outputs and evidence, not source code |

---

## D. Validation Order

1. clean-build the ROS 2 package;
2. launch with `execute_motion:=false`;
3. inspect RGB, depth, CameraInfo, encodings, rates, and QoS;
4. verify the fixed-frame-to-camera optical TF at the image timestamp;
5. trigger and inspect one stationary PLY;
6. publish and view latest/global ROS 2 point clouds;
7. identify the UR5e controller action and six-joint state source;
8. dry-run or visualize the raster without executing motion;
9. perform one supervised low-speed move and second capture;
10. compare TF-only and TF+ICP alignment;
11. complete a small indoor raster;
12. record a ROS 2 bag and replay offline;
13. collect orchard data only after the indoor pipeline is repeatable.

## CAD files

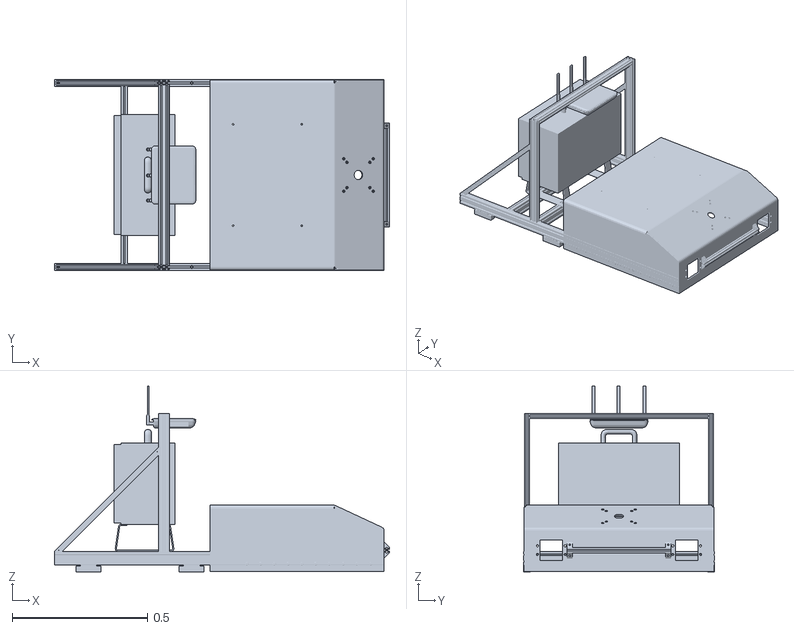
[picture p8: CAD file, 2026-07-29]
src/corn37_description/meshes/mount_frame.STL
1.24 x 0.705 x 0.685

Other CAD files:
src/arm_scan_motion/meshes/electric_pruner.stl

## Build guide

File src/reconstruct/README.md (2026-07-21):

# reconstruct — ROS 2 Humble / Gazebo Fortress

This package replaces the ROS 1 `rospy`, `actionlib`, `tf`, `ros_numpy`, catkin,
and global parameter-server code with ROS 2 Humble equivalents.

## What it does

1. `motion_planner.py` uses cuRobo to generate an **absolute**, snake-pattern
   raster around the UR5e's initial end-effector pose.
2. It sends each trajectory to a ROS 2
   `control_msgs/action/FollowJointTrajectory` action server.
3. After motion settles, it requests one synchronized Jetson RGB-D capture and
   waits for `/capture_done` before moving again.
4. `pointcloud_processing.py` uses the aligned Jetson depth/color streams,
   looks up `target_frame <- camera optical frame` in TF2 at the image stamp,
   performs optional local-map multi-scale ICP, publishes the global cloud, and
   continuously writes:

   `~/tree_scans/indoor_model_tree/global_point_cloud.ply`

## Required preflight checks

Your supplied topic list contains the Jetson RGB-D inputs, `/tf`, `/tf_static`,
and `/platform/joint_states`, but it does **not prove that the UR5e trajectory
action is running**. Topics do not list actions or services.

Run:

```bash
ros2 topic echo /platform/joint_states --once
ros2 action list -t | grep follow_joint_trajectory
ros2 control list_controllers
ros2 run tf2_ros tf2_echo base_link <camera_optical_frame>
ros2 topic hz /sensors/camera_jetson/color/image_raw
ros2 topic hz /sensors/camera_jetson/aligned_depth_to_color/image_raw
ros2 topic echo /sensors/camera_jetson/aligned_depth_to_color/camera_info --once
```

The joint-state message must contain all six UR5e joints. For Gazebo Fortress
with `gz_ros2_control`, the normal action is:

```text
/joint_trajectory_controller/follow_joint_trajectory
```

For the real Universal Robots ROS 2 driver, it is commonly:

```text
/scaled_joint_trajectory_controller/follow_joint_trajectory
```

The selected controller must already be loaded and `active`; this package does
not guess which other controller is safe to deactivate on your Warthog.

## Gazebo clock

The provided topic list does not show `/clock`. When `use_sim_time:=true`, a
Gazebo Fortress simulation needs a ROS clock. Ensure your Gazebo launch or
`ros_gz_bridge` exposes `/clock`; otherwise launch this package with
`use_sim_time:=false` only when all publishers are using wall time.

## Build

```bash
cd ~/ros2_ws/src
cp -r /path/to/reconstruct_ros2_humble ./reconstruct
cd ~/ros2_ws
rosdep install --from-paths src --ignore-src -r -y
colcon build --symlink-install --packages-select reconstruct
source install/setup.bash
```

Install non-ROS Python dependencies in the same Python environment used by ROS:

```bash
python3 -m pip install open3d
# Install cuRobo using the NVIDIA instructions appropriate to your CUDA/Jetson setup.
```

## Safe first run: reconstruction only

Keep the arm still and trigger one frame manually:

```bash
ros2 launch reconstruct scan_tree.launch.py execute_motion:=false use_sim_time:=true
```

In another terminal:

```bash
ros2 topic pub --once /capture_alert std_msgs/msg/Bool "{data: true}"
```

Then inspect:

```bash
ls -lh ~/tree_scans/indoor_model_tree/global_point_cloud.ply
rviz2
```

In RViz, set **Fixed Frame** to `base_link`, add a **PointCloud2** display, and
select `/tree_scan/global_cloud`.

## Motion run

Before enabling motion, place the arm at a collision-checked starting pose with
the Jetson camera facing the model tree at the desired standoff. The scan keeps
that tool orientation and translates over a raster around the current pose. The
default raster axes are tool-frame X/Y; change `scan_axis_u_ee` and
`scan_axis_v_ee` if the camera mount is rotated relative to the tool.

Only after the preflight checks and a reconstruction-only capture work:

```bash
ros2 launch reconstruct scan_tree.launch.py execute_motion:=true use_sim_time:=true
```

Tune scan size, axes, depth, voxel size, and ICP in `config/params.yaml`. Use a
new `scan_id` for each experiment if you want to retain every run.

## Remaining physical-model requirements

Code cannot infer these from a topic list:

- The exact UR5e trajectory action name and whether its controller is active.
- Whether `/platform/joint_states` includes the six arm joints.
- The `base_link -> ... -> camera optical frame` TF chain.
- The calibrated camera-to-tool transform.
- The camera housing geometry in the cuRobo collision model.
- The actual room/tree/table collision geometry. The default
  `collision_table.yml` is only a floor slab.

For real hardware, add the camera mount/housing to the URDF and cuRobo collision
spheres, and replace the world YAML with measured obstacles before increasing
scan dimensions.

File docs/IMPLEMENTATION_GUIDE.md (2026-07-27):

# Discrete RGB-D Acquisition and Repeatable Filter Evaluation

## What changed

The revised path keeps Dawood's validated motion controller and adds one
pose-specific capture transaction:

1. The trajectory action reports success.
2. The executor waits `capture_settle_time_ms`.
3. It publishes pose ID `N` as `std_msgs/msg/UInt32`.
4. Reconstruction discards synchronized frames timestamped before the request.
5. It collects five new exact-TF RGB-D samples.
6. It computes a zero-aware per-pixel median depth.
7. It saves the raw burst before depth cropping, voxelization, outlier removal,
   or ICP.
8. It returns `+N` when the reconstructed pose is accepted or `-N` when it is
   rejected.
9. The arm advances only after `+N`. A rejection or timeout stops before the
   next motion.

The topics are:

```text
/tree_scan/capture_request  std_msgs/msg/UInt32
/tree_scan/capture_result   std_msgs/msg/Int32
/tree_scan/scan_finished    std_msgs/msg/Bool
```

## File placement

Place the revised files at:

```text
cornell-warthog-sim/src/reconstruct/scripts/pointcloud_processing.py
cornell-warthog-sim/src/reconstruct/scripts/compare_filters.py
cornell-warthog-sim/src/reconstruct/config/params.yaml
cornell-warthog-sim/src/reconstruct/launch/scan_tree.launch.py

dawood_tree_scanning_ur5e/src/arm_scan_motion/src/scanning_trajectory.cpp
dawood_tree_scanning_ur5e/src/arm_scan_motion/src/scanning_trajectory_node.cpp
```

The two package `CMakeLists.txt` files and `package.xml` files still need to be
checked. The C++ targets now require `std_msgs`; the reconstruction package must
install `compare_filters.py`.

## First validation sequence

Build and source both workspaces in the same order used by the lab. Start
Dawood's bringup first:

```bash
ros2 launch arm_scan_motion bringup.launch.py
```

Start reconstruction with the revised parameter file:

```bash
ros2 launch reconstruct scan_tree.launch.py \
  params_file:=$HOME/dev/cornell-warthog-sim/src/reconstruct/config/params.yaml \
  use_sim_time:=false
```

Set a unique `scan_id` in `params.yaml` for each physical acquisition. Reusing
one directory across separate 32-pose runs would mix capture attempts in the
offline comparison.

Before moving the robot, test one stationary capture:

```bash
ros2 topic echo /tree_scan/capture_result
```

In another terminal:

```bash
ros2 topic pub --once \
  /tree_scan/capture_request \
  std_msgs/msg/UInt32 "{data: 1}"
```

Expected result:

```text
data: 1
```

A negative result means the capture was rejected; inspect
`~/tree_scans/<scan_id>/raw/capture_0001/capture.json`.

For the first supervised motion test, use one step:

```bash
ros2 run arm_scan_motion scanning_trajectory --ros-args \
  --params-file $HOME/dev/cornell-warthog-sim/src/reconstruct/config/params.yaml \
  -p max_steps:=1
```

Only proceed to all 32 steps after the result handshake and saved raw data have
been confirmed.

## Raw baseline

Each capture directory contains:

```text
frame_00_color.png
frame_00_depth.npy
frame_00_depth.png       # when the source is 16UC1
...
selected_color.png
median_depth_m.npy
median_depth_mm.png
median_valid_counts.npy
raw_camera_cloud.ply
raw_target_cloud.ply
capture.json
```

`capture.json` contains the camera intrinsics, every sensor timestamp, each
exact `target_frame <- camera_frame` transform, a joint-state snapshot, depth
units, crop bounds, ICP result, and acceptance reason.

This pose-level archive supports filter comparisons. A rosbag remains useful
as the complete audit trail:

```bash
ros2 bag record -o ~/tree_scans/raw_scan_$(date +%Y%m%d_%H%M%S) \
  /sensors/camera_jetson/color/image_raw \
  /sensors/camera_jetson/aligned_depth_to_color/image_raw \
  /sensors/camera_jetson/aligned_depth_to_color/camera_info \
  /tf /tf_static /joint_states \
  /tree_scan/capture_request \
  /tree_scan/capture_result
```

Add color/depth metadata topics if they exist in `ros2 topic list`.

## Offline filter comparison

Run:

```bash
python3 /path/to/compare_filters.py \
  ~/tree_scans/indoor_model_tree
```

It creates a timestamped directory containing:

```text
none/global_point_cloud.ply
current_radius/global_point_cloud.ply
dawood_radius/global_point_cloud.ply
statistical/global_point_cloud.ply
comparison.csv
```

Profiles:

| Profile | Local voxel | Outlier method |
| --- | ---: | --- |
| `none` | Current value, initially 6 mm | None |
| `current_radius` | 6 mm | 6 neighbors within 20 mm |
| `dawood_radius` | 8 mm | 8 neighbors within 14 mm |
| `statistical` | 6 mm | 20 neighbors, standard-deviation ratio 2.0 |

To isolate TF placement from ICP:

```bash
python3 /path/to/compare_filters.py \
  ~/tree_scans/indoor_model_tree \
  --no-icp
```

Point count, ICP fitness, and RMSE are recorded, but visual sharpness,
thin-branch retention, apple completeness, and doubled-surface thickness must
also be inspected.

## Target-relative crop

The optional crop is a fixed axis-aligned box in `target_frame` (`base_link`).
It is disabled by default because the target has not yet been measured.

The easiest initial mode is:

```yaml
target_crop_enabled: true
target_center_mode: camera_forward
target_distance_m: <camera optical center to canopy center>
target_box_size_m: [<base X size>, <base Y size>, <base Z size>]
```

At the first capture, the code projects `[0, 0, target_distance_m]` along the
camera optical `+Z` axis into `base_link`, then locks that center for the whole
scan. Later arm poses do not move the crop.

Measuring camera-to-trunk distance is a reasonable first estimate if the trunk
plane is near the canopy center. It is not itself the crop's far limit. For an
estimated canopy thickness `T` and safety margin `M` on each side:

```text
box depth = T + 2M
near target depth ≈ center distance - box depth / 2
far target depth  ≈ center distance + box depth / 2
```

Start with a deliberately generous width/depth/height box that removes the lab
wall, floor, and robot while retaining all foliage. This is per-scan target
localization, not fitting filter parameters to one laboratory image.

If the first camera pose is not aimed through the target center, use:

```yaml
target_center_mode: fixed_target_frame
target_center_target_frame_m: [x, y, z]
```

## RealSense resolution and tuning

The `640 x 480` values in `warthog_ur5e_fixed_wheels.urdf` configure the Gazebo
sensor only. The physical stream is configured by the RealSense ROS node on the
Jetson. The reconstruction code does not resize either image; it uses the
received dimensions and `CameraInfo`.

Inspect the physical stream:

```bash
ros2 topic echo \
  /sensors/camera_jetson/aligned_depth_to_color/camera_info \
  --once

ros2 topic hz \
  /sensors/camera_jetson/aligned_depth_to_color/image_raw

ros2 node list | grep -i camera
ros2 param get <camera_node> depth_module.depth_profile
ros2 param get <camera_node> rgb_camera.color_profile
```

On the Jetson, `rs-enumerate-devices -c` lists supported profiles. Intel's D435
tuning guidance identifies `848 x 480` as the optimal native depth resolution
and warns that lower native resolution reduces depth precision. Because this
pipeline uses depth aligned to color, the aligned topic normally takes the
color stream's dimensions. Test matching supported color/depth profiles and
confirm throughput before changing the systemd service.

The D400 datasheet makes Min-Z resolution-dependent for the
D430/D435/D435i/D435f/D435if family: approximately 280 mm at `1280 x 720`,
195 mm at `848 x 480`, and 175 mm at `640 x 480` under its base settings.
`min_depth_m: 0.30` is therefore a conservative software validity guard, not a
claim that the 640-by-480 stream physically cannot see anything closer.

Do not enable several RealSense filters at once. First archive an unfiltered
scan, then test one setting at a time under the same range and lighting.

## Clock synchronization

Run these read-only checks on the laptop, Jetson, and any Linux robot computer
that publishes timestamped ROS data:

```bash
hostnamectl --static
date --iso-8601=ns
timedatectl show -p NTPSynchronized -p NTP -p TimeUSec

systemctl is-active chrony || \
systemctl is-active chronyd || \
systemctl is-active systemd-timesyncd

chronyc tracking
chronyc sources -v
chronyc sourcestats -v

grep -RHE \
  '^[[:space:]]*(server|pool|peer|refclock|allow|local|makestep)[[:space:]]' \
  /etc/chrony/chrony.conf /etc/chrony/conf.d 2>/dev/null
```

The selected source in `chronyc sources -v` is marked `^*`. Compare its
hostname/IP across the computers and compare the reported system offsets. Do
not replace the configuration with public NTP until the lab confirms whether
one host is the local master and whether the robot network is isolated.

Also identify which host stamps `/joint_states`:

```bash
ros2 topic info /joint_states -v
```

In the supplied bringup, the UR driver runs on the laptop, so the laptop and
Jetson are the critical clocks unless another computer publishes robot TF or
joint data. Do not try to install chrony on the UR control box merely because it
is a "robot computer."

## Calibration validation

There are three separate calibrations:

1. **UR5e kinematics** — `ur5e_calibration.yaml`, extracted from the physical
   robot.
2. **RealSense intrinsics and RGB-depth calibration** — supplied by the camera
   and reported in `CameraInfo`.
3. **Eye-in-hand extrinsic** — the rigid
   `pruner_link -> camera_jetson_*` transform in the URDF.

The URDF currently says the camera location was CAD-measured and instantiates:

```xml
<xacro:sensor_d435 parent="pruner_link" name="camera_jetson"
                    use_nominal_extrinsics="true">
  <origin xyz="0.069957 0.003698 0.101951" rpy="3.18 -1.57 0"/>
</xacro:sensor_d435>
```

That is a candidate extrinsic, not a validation result.

### Practical validation

1. Fix an AprilTag/ChArUco/checkerboard target rigidly in the workspace.
2. Verify intrinsics and depth against its measured plane at several ranges:
   valid-depth percentage, median range error, and plane-fit RMSE.
3. Acquire at least 8-15 varied arm poses with substantial orientation change.
4. Solve the eye-in-hand transform with a ROS 2 hand-eye tool such as
   `easy_handeye2`, or an equivalent lab procedure.
5. Compare the solved transform with the URDF, then run a TF-only reconstruction
   (`use_icp: false`). A rigid target should coincide across poses without
   systematic double surfaces.
6. Re-enable ICP and inspect the saved correction distribution. A consistent
   correction in one direction indicates an extrinsic problem; it should not be
   hidden by larger ICP limits.

Only after those checks should `max_icp_correction_translation_m` and
`max_icp_correction_rotation_deg` be evaluated near `0.03` and `5.0`. Those are
rejection guards, not calibration tolerances.

## Controller choice

The revised executor deliberately continues to send:

```text
/joint_trajectory_controller/follow_joint_trajectory
```

This matches Dawood's `bringup.launch.py`, whose
`initial_joint_controller` is `joint_trajectory_controller`. The earlier
`scaled_joint_trajectory_controller` requirement came only from the generated
cuRobo planner's parameter file.

The UR scaled controller can account for teach-pendant and safety speed scaling
when advancing trajectory time, but it does not improve RGB-D or point-cloud
quality. Changing controllers is unnecessary for these acquisition changes.
The revised replay instead gives an unscaled trajectory up to ten times its
nominal duration plus ten seconds to finish (important with the pendant at
20%); if that limit is exceeded, it requests goal cancellation before stopping.

Useful read-only checks:

```bash
ros2 control list_controllers
ros2 action list | grep follow_joint_trajectory
```

If the lab later chooses the scaled controller, it normally comes from the
installed UR driver/controller packages and can be selected as
`initial_joint_controller:=scaled_joint_trajectory_controller`; the action
name in the executor must then change too. Make that as a separate supervised
motion-system change, not as part of reconstruction tuning.

## Primary references

- Universal Robots scaled controller:
  <https://docs.universal-robots.com/Universal_Robots_ROS2_Documentation/doc/ur_robot_driver/ur_controllers/doc/index.html>
- Universal Robots calibration extraction:
  <https://docs.universal-robots.com/Universal_Robots_ROS2_Documentation/doc/ur_robot_driver/ur_calibration/doc/index.html>
- RealSense ROS wrapper launch parameters:
  <https://github.com/IntelRealSense/realsense-ros/blob/ros2-master/realsense2_camera/launch/rs_launch.py>
- RealSense D435 tuning guidance:
  <https://dev.realsenseai.com/docs/tuning-depth-cameras-for-best-performance/>
- RealSense D400 series datasheet:
  <https://www.realsenseai.com/wp-content/uploads/2023/10/Intel-RealSense-D400-Series-Datasheet-September-2023.pdf>
- RealSense D400 calibration tools:
  <https://dev.realsenseai.com/docs/calibration/>
- chrony documentation:
  <https://chrony-project.org/documentation.html>
- ROS 2 hand-eye calibration:
  <https://github.com/marcoesposito1988/easy_handeye2>

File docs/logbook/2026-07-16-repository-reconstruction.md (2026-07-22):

# 2026-07-16 — Repository Reconstruction and Configuration Audit

## Objective

Create a clean repository for reconstructing and extending the inherited orchard simulation work, organize the recovered material into a maintainable structure, and begin identifying which configurations and packages represent the latest working system.

The official handoff with Nidhish had not yet occurred and was scheduled for Friday, so all conclusions remained provisional.

## Work Completed

### Created the project repository

Created a new GitHub repository named:

`orchard-autonomy-sim`

The repository is intended to become a reproducible ROS 2 and Gazebo platform for Warthog simulation, mapping, perception, navigation, and evaluation in orchard environments.

Rather than copying Nidhish’s complete workspaces directly, I created a clean scaffold designed to separate:

* ROS packages;
* simulation worlds and models;
* robot and sensor configuration;
* launch files;
* evaluation tools;
* experiment results;
* daily research notes;
* formal documentation;
* external dependencies;
* inherited-file provenance.

The repository was created as a reconstruction and integration workspace, not yet as an authoritative replacement for Nidhish’s original project.

## Initial Repository Structure

```text
orchard-autonomy-sim/
├── README.md
├── LICENSE
├── CITATION.cff
├── CONTRIBUTING.md
├── SECURITY.md
├── .gitignore
├── .gitattributes
├── orchard_autonomy_sim.repos
├── docs/
│   ├── project_charter.md
│   ├── architecture.md
│   ├── setup.md
│   ├── quickstart.md
│   ├── troubleshooting.md
│   ├── known_issues.md
│   ├── inherited_work.md
│   ├── provenance.md
│   ├── handoff_questions.md
│   ├── workflows/
│   ├── evaluation/
│   ├── logbook/
│   └── figures/
├── src/
│   ├── orchard_description/
│   ├── orchard_bringup/
│   ├── orchard_perception/
│   ├── orchard_evaluation/
│   └── orchard_nav_integration/
├── config/
│   ├── robot/
│   ├── sensors/
│   ├── slam/
│   ├── nav2/
│   └── evaluation/
├── worlds/
├── models/
├── launch/
├── scripts/
│   ├── setup/
│   ├── run/
│   ├── evaluation/
│   └── migration/
├── tests/
├── experiments/
├── tools/
└── external/
```

This structure is intentionally broader than the current implementation. Only the directories needed for the first reproducible simulation will be populated initially.

## Migration Strategy

Decided not to copy the complete inherited workspaces directly because they contain:

* generated `build`, `install`, and `log` directories;
* absolute paths tied to Nidhish’s home directory;
* multiple generations of worlds and scripts;
* large maps, datasets, bags, and model checkpoints;
* third-party repositories;
* hardware-specific configuration;
* unclear file provenance and licensing.

The first migration should instead include only:

1. the relevant orchard-description package;
2. the current orchard world and required assets;
3. the latest Warthog simulation launch workflow;
4. a sanitized or clearly labeled simulation robot configuration;
5. teleoperation support;
6. the required mapping configuration;
7. setup and troubleshooting documentation.

Third-party packages such as LIO-SAM should be referenced using a `.repos` file or pinned external dependency rather than copied as original project code.

## Robot Configuration Audit

Inspected several `robot.yaml` configurations.

The files are not simply robot models. They define a particular Clearpath robot deployment, including:

* robot namespace;
* sensor types;
* mounting transforms;
* sensor launch behavior;
* hardware drivers;
* networking;
* generated URDF and launch configuration.

Different researchers appear to have maintained separate versions because they were using different experimental configurations.

### Current `/etc/clearpath/robot.yaml`

The current system configuration defines a simulated Warthog with:

* an Ouster OS1 3D LiDAR;
* a Microstrain IMU;
* three Intel RealSense cameras;
* a front camera;
* left- and right-facing cameras;
* simulation namespace `w200_0000`.

This configuration appears closest to Nidhish’s later three-camera orchard-mapping workflow and is likely the correct initial simulation configuration.

### Other robot configurations

One inspected configuration appeared closer to a physical Ouster deployment because it included:

* sensor IP addresses;
* UDP destination addresses;
* LiDAR and IMU ports;
* Clearpath discovery-server settings.

Another configuration contained:

* custom structural boxes;
* a tower;
* a primary RealSense camera;
* an overhead camera mounted four meters above the robot.

That version appears to be an experimental simulation or data-collection fixture rather than a realistic physical Warthog configuration.

## Configuration Handling Decision

For the private reconstruction repository, sensor types and mounting transforms can be retained.

For any eventual public release:

* real sensor IP addresses;
* hostnames;
* network topology;
* device-specific deployment values

should be removed or converted to placeholders.

The repository should distinguish among:

```text
config/clearpath/
├── robot.sim.yaml
├── robot.hardware.example.yaml
└── README.md
```

The exact physical deployment file should remain outside the public repository or in a private lab configuration repository.

## Orchard Description Inspection

Inspected Nidhish’s `orchard_description` package.

The package contains:

* multiple orchard worlds;
* aggregate orchard meshes;
* individual tree meshes;
* collision meshes;
* dormant, growing, flat, high-resolution, and uneven orchard variants;
* teleoperation and world-generation scripts;
* temporal camera–LiDAR projection code;
* Python and C++ perception implementations.

The asset directory contains several overlapping naming conventions and likely represents multiple development iterations. The final repository should include only assets referenced by the selected current world.

## Issues Identified in `orchard_description`

### Stale Gazebo Classic launch path

`launch/orchard_launch.py` launches:

```python
gazebo --verbose ... -s libgazebo_ros_factory.so
```

This is a Gazebo Classic workflow.

The recovered machine instead uses:

* Ubuntu 22.04;
* ROS 2 Humble;
* Ignition Gazebo Fortress;
* `clearpath_gz`.

The latest documented workflow launches the environment through:

```bash
ros2 launch clearpath_gz simulation.launch.py
```

Therefore, `orchard_launch.py` is likely an older or abandoned launch path and should not be used as the first reproduction target.

### Stale GPU comment

The launch file contains a comment referring to an RTX 4060 even though the current machine uses RTX 5000 Ada GPUs.

The underlying environment variables are generic NVIDIA rendering variables, so the comment is stale but not itself a functional problem.

### Packaging issue for `.world` files

`setup.py` installs:

```python
glob('worlds/*.sdf')
```

but does not install `.world` files.

Because the old launch file attempts to load `orchard.world`, that file may be missing from the installed package share directory after a clean build.

### Likely broken Python entry point

The package declares:

```python
custom_teleop = orchard_description.custom_teleop:main
```

but the script appears under:

```text
scripts/custom_teleop.py
```

rather than inside the importable `orchard_description` Python module.

This explains why the inherited workflow runs the script directly with Python rather than through `ros2 run`.

### Asset duplication and provenance

The package contains many duplicated or historical tree assets, including several naming styles and both aggregate and individual collision meshes.

The exact assets used by the latest world must be identified before migration. The package’s Apache-2.0 declaration does not by itself establish redistribution rights for all imported meshes and textures.

## ROS Dependency Audit

Ran:

```bash
rosdep check --from-paths src --ignore-src -r
```

After updating the rosdep cache, the remaining unresolved dependency was:

```text
ros-humble-gazebo-ros
```

This does not mean ROS 2 Humble or Gazebo are missing.

The machine already contains:

* ROS 2 Humble;
* Ignition Gazebo Fortress;
* Clearpath Gazebo packages;
* ROS–Gazebo bridge packages.

Instead, one package in the inherited workspace appears to declare a dependency on `gazebo_ros`, which belongs to the Gazebo Classic integration stack.

This suggests the workspace contains a mixture of:

* older Gazebo Classic code;
* newer Ignition Gazebo / Clearpath code.

The package declaring `gazebo_ros` must be identified before installing additional simulator packages. The likely candidate is the older `orchard_worlds` simulation package.

## Current Technical Interpretation

The latest likely simulation workflow is:

```text
/etc/clearpath/robot.yaml
        ↓
Clearpath robot generators
        ↓
Generated Warthog description and sensors
        ↓
clearpath_gz simulation.launch.py
        ↓
Ignition Gazebo Fortress orchard world
        ↓
Warthog, LiDAR, IMU, and camera ROS topics
```

The older `orchard_launch.py` and any `gazebo_ros` dependencies likely belong to an earlier development path.

## Decisions

* Keep the new repository private during reconstruction.
* Treat the recovered files as an unofficial handoff until the Friday meeting.
* Do not modify Nidhish’s original directories.
* Do not install Gazebo Classic solely to satisfy the current rosdep warning.
* Use `/etc/clearpath/robot.yaml` as the provisional simulation configuration.
* Build `orchard_description` separately before attempting the entire inherited workspace.
* Launch through `clearpath_gz`, not the stale Gazebo Classic launch file.
* Keep hardware-specific configuration separate from simulation examples.
* Track imported files and authorship in `docs/provenance.md`.

## Questions for Nidhish

1. Which workspace represents the final intended project?
2. Are `cornell_orchard_ws` and `orchard_navigation_rl_ws` intended to run together?
3. Which orchard world is the latest working version?
4. Is `/etc/clearpath/robot.yaml` the intended simulation configuration?
5. Which robot YAML corresponds to the physical Warthog?
6. Is `orchard_launch.py` obsolete?
7. Is the `gazebo_ros` dependency still required?
8. Was Gazebo Classic used at any point in the final workflow?
9. Which tree meshes and textures may be redistributed?
10. Which files were changed locally but never committed?
11. What exact launch sequence produced the latest successful simulation?
12. Which components should be migrated into the new repository?
13. Was the learned policy ever evaluated closed-loop in Gazebo?
14. What specific deliverable would be most useful for publication?

## Next Actions

1. Locate the package declaring the `gazebo_ros` dependency.
2. Build only `orchard_description` from a clean copy.
3. Source ROS 2 Humble and the rebuilt workspace.
4. Launch the orchard through `clearpath_gz`.
5. Verify Warthog spawning and teleoperation.
6. Record all ROS nodes, topics, transforms, and sensor streams.
7. Compare the observed system with the inherited documentation.
8. Bring the reconstructed architecture, blocker list, and targeted questions to the Friday handoff meeting.

## End-of-Day Status

The project now has a clean repository and a migration plan.

The inherited system appears more developed than initially expected, but it contains multiple generations of simulation code and configuration. The primary immediate task is no longer creating a Gazebo environment from scratch. It is identifying, reproducing, and consolidating the latest valid Clearpath Warthog orchard-simulation workflow without carrying forward obsolete code or undocumented machine-specific assumptions.

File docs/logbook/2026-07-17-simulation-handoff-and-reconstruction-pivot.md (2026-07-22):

# 2026-07-17 — Simulation Reproduction, Technical Handoff, and Project Scope Pivot

## Objective

Reproduce enough of the inherited Warthog orchard-simulation stack to determine whether it is technically viable, complete the formal handoff with Divyanth and Nidhish, identify the authoritative source repository, and obtain a concrete definition of success for the remainder of the Cornell visit.

The day began with the assumption that my primary contribution would involve reproducing and extending the Gazebo orchard environment.

Following the handoff meeting, the project scope changed substantially. My primary responsibility is now to inherit Dawood’s existing tree-reconstruction algorithm, remove unnecessary components, migrate the required workflow to ROS 2, connect it to the Warthog’s RGB-D camera, and produce several reconstructed leafy-tree models before leaving Cornell.

Gazebo integration is now a downstream objective rather than the immediate focus.

---

## Work Completed

### Reproduced the inherited ROS workspace from a clean build

Performed a clean build of the recovered:

```text
cornell_orchard_ws
```

using:

```bash
source /opt/ros/humble/setup.bash

rm -rf build install log

colcon build \
  --symlink-install \
  --event-handlers console_direct+ \
  2>&1 | tee build-reproduction.log
```

The workspace contains three ROS 2 packages:

```text
lio_sam
orchard_description
orchard_perception
```

The build completed successfully:

```text
Summary: 3 packages finished
```

This established that the recovered workspace is fundamentally buildable under:

* Ubuntu 22.04;
* ROS 2 Humble;
* Ignition Gazebo Fortress;
* Python 3.10;
* the Clearpath Humble simulation stack.

The remaining warnings were primarily package-maintenance and dependency warnings rather than compilation failures.

---

### Reproduced the core Warthog simulation workflow

Launched the inherited orchard world through:

```bash
ros2 launch clearpath_gz simulation.launch.py
```

using the recovered Clearpath Warthog configuration and the orchard world under `orchard_description`.

The launch progressed far enough to confirm that:

* Gazebo Fortress loaded the requested orchard world;
* the Warthog entity was created successfully;
* the generated Warthog URDF was published;
* `robot_state_publisher` loaded the robot frame tree;
* `gz_ros2_control` initialized the four wheel joints;
* the controller manager started;
* the LiDAR bridge started;
* three RGB-D camera bridges started;
* RGB-D point-cloud bridges started;
* IMU bridges started;
* teleoperation and command-multiplexing nodes started.

This demonstrated that the inherited simulator is not fundamentally broken.

The primary remaining failures were:

1. hard-coded absolute file paths;
2. Clearpath generator permissions under `/etc/clearpath`;
3. machine-specific launch configuration;
4. unresolved differences between the GitHub repository and the recovered desktop workspace.

---

## Simulation Defects Identified

### Clearpath setup-directory permissions

The simulator attempted to generate files under:

```text
/etc/clearpath/
```

including:

```text
robot.urdf.xacro
robot.srdf.xacro
generated sensor launch files
generated camera parameter files
```

These writes failed under the normal user account because `/etc/clearpath` is root-owned.

The simulator continued only because previously generated files were already present.

The portable solution is to copy the simulation configuration to a user-writable directory such as:

```text
~/clearpath_sim/
```

and pass that directory through the `setup_path` launch argument.

ROS and Gazebo should not be launched with `sudo`.

---

### Absolute paths tied to previous users

The world, model, and launch files contain paths associated with multiple machines and accounts, including:

```text
/home/divyanth/...
/home/nidhish/...
/home/nidhish27/...
```

This suggests that the project was moved between Divyanth’s laptop and Nidhish’s workstation without being fully made portable.

Replacing these paths with `/home/david/...` would only create another machine-specific version.

The correct long-term solution is to use:

* `model://` URIs for Gazebo assets;
* `IGN_GAZEBO_RESOURCE_PATH` for model discovery;
* `ament_index_python` and `get_package_share_directory()` for ROS package files;
* launch arguments for Clearpath setup directories;
* installed package paths instead of source-tree home-directory paths.

Because the project scope changed during the meeting, this portability cleanup is no longer the immediate research priority. The findings should still be preserved for later simulator integration.

---

## Formal Handoff Meeting

Met with:

* Divyanth Loganathan Girija;
* Nidhish Kumar.

This was the first full technical handoff with Nidhish.

I explained that, after receiving administrator access to the lab desktop, I located his ROS workspaces while searching for the existing ROS and Gazebo installation. I copied the workspaces into my own directory for inspection and left the original directories untouched.

Nidhish accepted this explanation and clarified the organization of his work.

---

## Workspace Authority Clarified

Nidhish identified:

```text
cornell_orchard_ws
```

as the primary workspace relevant to the simulator.

Its three packages are:

### `lio_sam`

Used to combine LiDAR and IMU measurements for pose estimation and map creation.

The primary project-specific configuration is contained in:

```text
src/LIO-SAM/config/params.yaml
```

Most of the remaining package is inherited upstream LIO-SAM code.

### `orchard_description`

Contains:

* orchard worlds;
* tree models;
* ground meshes;
* visual and collision assets;
* scripts used to generate orchard layouts;
* multiple dormant and high-resolution world variants.

Nidhish identified the dormant-orchard and new-tree generation scripts as the most relevant environment-generation code.

### `orchard_perception`

Contains:

* camera–LiDAR projection and fusion;
* the principal launch orchestration;
* RViz configuration;
* the temporal-projector implementation.

Nidhish indicated that the main launcher coordinates the simulator, mapping, perception, and visualization components.

---

## Workspace Deprioritized

The second recovered workspace:

```text
orchard_navigation_rl_ws
```

contains the prior behavior-cloning and learned-navigation work, including:

* camera-only navigation;
* LiDAR-only navigation;
* multimodal navigation;
* model checkpoints;
* evaluation scripts;
* data collection;
* DAgger infrastructure;
* odometry diagnostics;
* offline policy metrics.

Nidhish characterized this as separate and earlier work.

It is not currently the authoritative workspace for my assignment and should not receive additional attention during the remaining Cornell visit unless Divyanth explicitly redirects the project again.

Therefore, the following tasks are now paused:

* learned-policy metric analysis;
* camera/LiDAR/multimodal ablations;
* closed-loop policy integration;
* Nav2 benchmarking;
* navigation-policy deployment;
* broad Gazebo evaluation infrastructure.

---

## Project Scope Changed

The most important result of the meeting was a substantial narrowing of the assignment.

My primary responsibility is no longer:

> Complete a general-purpose Gazebo navigation platform or benchmark autonomous navigation methods.

The revised assignment is:

> Build a reproducible 3D tree-reconstruction pipeline, use it to reconstruct several real leafy orchard trees while physically at Cornell, and export usable 3D assets that can later be inserted into Nidhish’s Gazebo orchard.

The immediate workflow is now:

```text
Dawood’s existing reconstruction algorithm
                ↓
Understand and reproduce the current pipeline
                ↓
Remove obsolete or unnecessary components
                ↓
Migrate the required workflow from ROS 1 to ROS 2
                ↓
Connect it to the Warthog RGB-D camera
                ↓
Validate it on an indoor artificial tree
                ↓
Collect real orchard-tree data
                ↓
Reconstruct several leafy tree models
                ↓
Export simulator-ready assets
                ↓
Future Gazebo integration and evaluation
```

Divyanth indicated that, with approximately ten working days remaining, a successful internship outcome would be:

* a functioning reconstruction codebase;
* successful integration with the Warthog’s RGB-D data;
* several reconstructed tree models;
* reusable documentation and code;
* preservation of the raw data required for later processing.

Insertion of every model into Gazebo is secondary and may be completed remotely after I return to UCF.

---

## Research Motivation

The current virtual orchard primarily represents dormant or winter trees.

The laboratory wants to evaluate agricultural perception or navigation systems under seasonal visual changes. Models trained or tested only in a dormant orchard may not generalize to:

* leafy canopies;
* green-fruit stages;
* denser foliage;
* different lighting and occlusion patterns;
* other seasonal appearances.

The immediate tree scans collected in July should be labeled by their actual phenological condition rather than automatically being called “spring” or “fall” models.

A realistic label may be:

```text
current-season leafy trees
```

or:

```text
green-fruit-stage trees
```

depending on the orchard condition at collection time.

---

## Publication Framing

Scanning trees and exporting meshes alone would probably be too small for a strong publication.

The broader publishable direction is:

> A multi-season, real-tree-derived orchard simulation environment for evaluating the seasonal robustness of agricultural perception and autonomous-navigation systems.

A complete future paper could include:

* reconstructed tree assets representing multiple seasonal stages;
* a reproducible data-capture and reconstruction methodology;
* reconstruction-quality measurements;
* integration of the assets into a simulation environment;
* evaluation of one or more algorithms across seasonal conditions;
* measurement of performance degradation caused by seasonal domain shift;
* experiments involving multi-season training or domain randomization.

My immediate work would provide the data and reconstruction infrastructure required for that larger experiment.

To preserve publication potential, I should continue owning more than the initial data collection. Potential continued responsibilities include:

* ROS 2 pipeline development;
* reconstruction evaluation;
* simulator integration;
* seasonal experiments;
* figures and visualizations;
* documentation;
* ablation studies;
* writing the methods and experimental sections.

---

## Revised Definition of Done

### Minimum deliverable

By the end of the Cornell visit:

* Dawood’s reconstruction workflow is reproduced;
* the required parts are migrated to ROS 2;
* unnecessary or obsolete code is removed or isolated;
* the node can consume the Warthog RGB-D stream;
* at least one indoor tree reconstruction succeeds;
* raw data from several real orchard trees is collected;
* at least two usable tree models are generated;
* the pipeline and required commands are documented.

### Target deliverable

* Three to six real trees are captured successfully;
* several reconstructed models are produced;
* visual and collision representations are considered separately;
* model scale and orientation are validated;
* raw inputs, camera information, parameters, and metadata are preserved;
* the complete pipeline can be repeated by another researcher;
* at least one model is prepared for later Gazebo insertion.

### Stretch deliverable

* Six to ten trees are captured;
* multiple tree models are integrated into the orchard;
* automated model/world generation is added;
* a dormant-versus-leafy comparison is performed;
* a preliminary seasonal-robustness experiment is completed.

---

## Repository Handoff and Audit

Nidhish shared a GitHub repository named:

```text
Spatio-Temporal-Mapping
```

The GitHub repository is now treated as the clean baseline, while the recovered desktop workspace is retained as a recovery source for possible uncommitted changes.

---

### Restored missing LIO-SAM submodule metadata

The repository tracked:

```text
src/LIO-SAM
```

as a Git submodule pointer at commit:

```text
08af3f32f01725372d4269838dc44c19c6d9e76b
```

However, the repository was missing the corresponding `.gitmodules` entry. A fresh clone therefore knew which commit was expected but did not know which repository contained it.

The recovered desktop copy confirmed the intended upstream repository:

```text
https://github.com/TixiaoShan/LIO-SAM.git
```

and was checked out at the exact expected commit.

Created a repair branch:

```text
fix/restore-lio-sam-submodule
```

Added:

```ini
[submodule "src/LIO-SAM"]
    path = src/LIO-SAM
    url = https://github.com/TixiaoShan/LIO-SAM.git
```

Verified the repair by performing a fresh recursive clone and confirming that LIO-SAM was automatically checked out at the intended commit.

The repair branch was pushed to Nidhish’s repository but was not merged into the default branch.

I should notify Nidhish, explain the repair, and ask whether he wants:

* a pull request;
* the branch retained without merging;
* or the branch removed.

---

### Downloaded Git LFS assets

Many tree meshes initially appeared as files of approximately 130 bytes.

These were Git LFS pointer files rather than actual geometry.

Installed Git LFS:

```bash
sudo apt install git-lfs
git lfs install
git lfs pull
```

After pulling the LFS objects, the files became full binary assets measured in megabytes.

This allowed the GitHub repository to be compared meaningfully against the recovered desktop workspace.

---

### Compared GitHub repository with recovered desktop copy

After initializing the submodule and downloading LFS assets, the two workspaces were largely similar.

The recovered desktop contained additional result artifacts:

```text
final_colored_orchard.pcd
frames_*.gv
frames_*.pdf
build-reproduction.log
```

These should be preserved as experimental outputs rather than merged directly into source control.

Important code differences remain in:

```text
LIO-SAM/config/params.yaml
LIO-SAM/config/rviz2.rviz
LIO-SAM/launch/run.launch.py

orchard_description/scripts/generate_orchard_new_trees.py
orchard_description/worlds/orchard_final_high_res.sdf

orchard_perception/launch/infrastructure.launch.py
orchard_perception/launch/main_launcher.py
orchard_perception/rviz/orchard_mapping.rviz
orchard_perception/src/temporal_projector.cpp
```

The two `temporal_projector.cpp` files appear to represent substantially different experimental implementations rather than simple path updates.

Because the project has pivoted toward reconstruction, these differences should be documented and preserved but not investigated deeply unless required later.

---

## RGB-D Camera and ROS 2 Integration Setup

Began preparing to connect Dawood’s reconstruction algorithm to the Warthog’s RGB-D camera.

The likely runtime architecture is:

```text
Warthog RGB-D camera
         ↓
Jetson Orin onboard computer
         ↓
ROS 2 camera driver publishes image and depth topics
         ↓
Laptop joins the same ROS 2 network
         ↓
RViz and reconstruction node subscribe to camera topics
         ↓
Reconstruction pipeline generates tree point cloud or mesh
```

The camera driver should run on the Jetson because the camera is physically connected to it.

The laptop should primarily be used for:

* visualization;
* development;
* reconstruction;
* rosbag recording;
* debugging;
* offline processing.

---

## WSL and ROS Environment Setup

My laptop initially used:

* a WSL Ubuntu environment;
* ROS 2 Jazzy.

The Jetson uses:

* Ubuntu 22.04;
* ROS 2 Humble.

Because cross-distribution communication is not a reliable basis for field data collection, installed a separate:

```text
Ubuntu-22.04
```

WSL distribution and configured the official ROS 2 repository.

Installed:

```text
ros-humble-desktop
ros-dev-tools
```

The intended environment is now:

```text
Laptop: Ubuntu 22.04 + ROS 2 Humble
Jetson: Ubuntu 22.04 + ROS 2 Humble
```

Configured WSL mirrored networking through:

```ini
[wsl2]
networkingMode=mirrored
firewall=true
```

Set the provisional ROS network configuration:

```bash
export ROS_DOMAIN_ID=10
export ROS_LOCALHOST_ONLY=0
```

---

## Connected to the Warthog ROS Network

After restarting WSL and correcting the ROS environment, remote ROS topics became visible using:

```bash
ros2 topic list --no-daemon
```

The discovered topics confirmed access to:

* Warthog platform status;
* motor status;
* battery information;
* emergency-stop status;
* odometry;
* filtered odometry;
* command velocity;
* joint states;
* robot description;
* TF;
* IMU;
* front RGB-D camera;
* Jetson RGB-D camera.

Relevant Jetson camera topics include:

```text
/sensors/camera_jetson/color/image_raw
/sensors/camera_jetson/color/camera_info

/sensors/camera_jetson/depth/image_rect_raw
/sensors/camera_jetson/depth/camera_info

/sensors/camera_jetson/aligned_depth_to_color/image_raw
/sensors/camera_jetson/aligned_depth_to_color/camera_info
```

Other available camera data include:

```text
/sensors/camera_0/color/image
/sensors/camera_0/depth/image
/sensors/camera_0/points
```

The full topic discovery proves that:

* WSL mirrored networking is functioning;
* the laptop is on the robot network;
* the ROS domain is correct;
* remote ROS 2 participant discovery works;
* the Jetson and Warthog publishers are visible.

---

## Current ROS Networking Issue

The normal ROS daemon remained stale or did not reflect the remote graph.

This command showed only local topics:

```bash
ros2 topic list
```

while this command showed the full remote graph:

```bash
ros2 topic list --no-daemon
```

Therefore, remote discovery is working, but the local ROS 2 daemon must be reset after the correct ROS domain and networking variables are loaded.

Planned reset:

```bash
source /opt/ros/humble/setup.bash
export ROS_DOMAIN_ID=10
export ROS_LOCALHOST_ONLY=0

ros2 daemon stop
pkill -f _ros2_daemon 2>/dev/null || true
ros2 daemon start
```

All environment variables should be set before starting the daemon.

---

## Current Camera Visualization Issue

Although the camera topics are visible, the image stream has not yet been displayed successfully in RViz.

Possible causes include:

* stale ROS daemon state;
* incompatible RViz QoS settings;
* best-effort camera publishing versus reliable subscription;
* camera topic visible through discovery but image packets not yet received;
* incorrect RViz image topic;
* use of the wrong camera stream;
* Wi-Fi limitations for large image or point-cloud messages.

The next validation command should measure whether actual messages are arriving:

```bash
ros2 topic hz \
  /sensors/camera_jetson/color/image_raw \
  --qos-profile sensor_data
```

Then test one message:

```bash
ros2 topic echo \
  /sensors/camera_jetson/color/image_raw \
  --qos-profile sensor_data \
  --once
```

In RViz, the Image display should use:

```text
Topic: /sensors/camera_jetson/color/image_raw
Reliability: Best Effort
Durability: Volatile
```

`rqt_image_view` can be used as a simpler camera-feed validation tool before debugging RViz further.

---

## Revised Priorities

### Highest priority

1. Obtain Dawood’s complete reconstruction code and documentation.
2. Identify the exact input topics and expected message types.
3. Determine what parts of the ROS 1 system are still necessary.
4. Remove unrelated or obsolete code.
5. Create a clean ROS 2 package.
6. Confirm live RGB and aligned-depth data from the Warthog.
7. Record a short rosbag containing all required inputs.
8. Run one indoor artificial-tree reconstruction.
9. Measure the time and quality of one complete reconstruction.
10. Schedule real orchard data collection.
11. Capture several trees while physically at Cornell.
12. Preserve all raw data and metadata.
13. Generate several usable tree models.
14. Document the complete workflow.

### Deprioritized

* broad Gazebo cleanup;
* Nav2 study;
* SLAM benchmarking;
* learned-navigation policy evaluation;
* simulation metrics;
* full seasonal orchard generation;
* optimization of Nidhish’s temporal projector;
* cleaning every historical world and model asset;
* general-purpose navigation evaluation.

---

## Questions for Dawood

1. Which repository contains the latest reconstruction algorithm?
2. Which branch or commit should be treated as authoritative?
3. Is the current implementation ROS 1, ROS 2, or partially independent of ROS?
4. What files and nodes are no longer required?
5. What exact RGB-D camera model was used?
6. Which topics does the algorithm subscribe to?
7. Does it consume:

   * RGB images;
   * aligned depth;
   * camera intrinsics;
   * point clouds;
   * TF;
   * odometry;
   * camera poses?
8. Does reconstruction run online or after data collection?
9. What output format does it produce?
10. How is the final mesh generated?
11. What coordinate frame, scale, and orientation are expected?
12. How was the camera moved around the tree?
13. How are multiple views registered?
14. Is external pose estimation required?
15. What calibration files are required?
16. What was the most recent successful test?
17. Which parameters are most sensitive?
18. What failure cases should I expect?
19. How long does one tree take to capture and process?
20. What minimum tree coverage is needed?
21. Should processing run on the Jetson, laptop, or lab desktop?
22. Which parts should I rewrite rather than directly port?

---

## Questions for Divyanth

1. What exact demonstration should I provide before leaving Cornell?
2. How many reconstructed trees are required for the minimum deliverable?
3. What actual seasonal label should be assigned to the July orchard trees?
4. Which orchard and tree variety should be scanned?
5. Who will help operate the Warthog during field collection?
6. Which robot platform and camera configuration should be used?
7. Should I collect six to ten trees only after validating one complete indoor reconstruction?
8. What metadata should be collected for every tree?
9. What future experiment will use the reconstructed assets?
10. Can I continue owning simulator integration and seasonal evaluation after returning to UCF?
11. What contribution would support authorship on a future paper?
12. Should the reconstruction work live in my repository, Dawood’s repository, or a lab-owned repository?

---

## Decisions

* The primary project is now tree reconstruction, not general Gazebo development.
* Dawood’s reconstruction algorithm should be inherited rather than rebuilt from scratch.
* Only the necessary components should be migrated to ROS 2.
* Data collection should be prioritized while I am physically at Cornell.
* A working indoor reconstruction should precede large-scale orchard collection.
* Raw RGB-D data should be recorded even if live reconstruction is available.
* The Jetson should publish hardware camera data.
* The laptop or lab desktop should perform heavier reconstruction unless the existing system requires Jetson execution.
* The GitHub `Spatio-Temporal-Mapping` repository is the clean simulator baseline.
* The recovered desktop workspace should remain an unmodified recovery source.
* Gazebo portability findings should be documented but not allowed to distract from the reconstruction deliverable.
* Publication potential depends on continuing from asset creation into evaluation, experiments, figures, and writing.

---

## Next Actions

1. Reset the ROS 2 daemon with the correct domain already exported.
2. Confirm a live frequency for the Jetson RGB topic.
3. Confirm aligned-depth frequency.
4. Display the image through `rqt_image_view` or RViz with best-effort QoS.
5. Inspect camera-info messages and frame IDs.
6. Record a short RGB-D rosbag.
7. Obtain Dawood’s code and latest run instructions.
8. Audit the code and separate:

   * required reconstruction logic;
   * ROS 1 interfaces;
   * obsolete scripts;
   * visualization-only code;
   * training or experimental remnants.
9. Design the ROS 2 package structure.
10. Run the pipeline on an indoor artificial tree.
11. Estimate capture and processing time per tree.
12. Set a realistic field-collection target.
13. Schedule the orchard trip and robot access.
14. Define the raw-data and model naming convention.
15. Prepare a Monday progress update with:

* live camera proof;
* reconstruction architecture;
* code-migration plan;
* blockers;
* field-data schedule.

---

## End-of-Day Status

The inherited simulator was reproduced far enough to prove that its core architecture is viable. All three primary packages built successfully, Gazebo loaded the orchard world, the Warthog spawned, its controllers initialized, and its simulated sensors were bridged into ROS 2.

The formal meeting with Divyanth and Nidhish then clarified that broad simulator development is not the best use of the remaining time at Cornell.

The project has been narrowed to a more realistic and physically dependent contribution:

> Inherit and clean Dawood’s tree-reconstruction algorithm, migrate the required workflow to ROS 2, connect it to the Warthog RGB-D camera, collect real leafy-tree data, and produce several reusable 3D tree models.

The simulator work completed earlier in the day remains valuable because it established the longer-term destination for the reconstructed assets and documented the inherited infrastructure. However, the immediate research priority is now the reconstruction pipeline and field-data collection.

The laptop is now running Ubuntu 22.04 with ROS 2 Humble, can discover the Warthog and Jetson ROS graph, and can see the required RGB-D topic names. The remaining immediate technical issue is validating actual image delivery and displaying the stream reliably in RViz or `rqt_image_view`.

The day ended with a substantially clearer and more achievable research objective than the one held at the start of the week.

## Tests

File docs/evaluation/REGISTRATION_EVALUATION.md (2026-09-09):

# TF-Anchored Registration Experiment

## Purpose

This experiment compares three registration architectures while holding the
selected captures, crop, filter, and voxel settings fixed:

1. TF-only fusion;
2. chronological frame-to-accumulated-cloud TF+ICP;
3. TF-anchored batch pose-graph optimization followed by one-time fusion.

It also replays incremental ICP in reverse and seeded shuffled orders. If only
the replay order changes but the estimated poses, accepted captures, or final
geometry change materially, accumulated-map ICP is order-dependent.

## Scripts

Keep these files beside one another:

```text
src/reconstruct/scripts/compare_filters.py
src/reconstruct/scripts/compare_registration.py
```

`compare_registration.py` imports the validated capture selection, crop,
filter, metric, and baseline-fusion functions from `compare_filters.py`.

## Required dataset layout

```text
<scan_dir>/
├── run_config.json
└── raw/
    ├── capture_0001/
    │   ├── capture.json
    │   └── raw_target_cloud.ply
    └── ...
```

For each request ID, the scripts prefer the highest-numbered accepted attempt.
If every attempt was rejected, they retain the latest attempt so it can still
be tested under another offline configuration.

The experiment needs Python 3, NumPy, Open3D 0.19, and Matplotlib. ROS nodes and
robot hardware do not need to be running.

## Baseline experiment

`compare_filters.py` provides controlled `tf_only` and `tf_icp` replays:

```bash
python3 src/reconstruct/scripts/compare_filters.py \
  "$HOME/dev/tree_scans/<scan_id>" \
  --profiles statistical \
  --registration-modes tf_only tf_icp \
  --local-voxel-size-m 0.003 \
  --global-voxel-size-m 0.003
```

Both modes consume the same selected captures in the same order.

## Fast pose-graph smoke test

```bash
python3 src/reconstruct/scripts/compare_registration.py \
  "$HOME/dev/tree_scans/<scan_id>" \
  --profiles statistical \
  --graph-priors nominal \
  --shuffle-count 1
```

This still runs TF-only, chronological TF+ICP, reverse ICP, one deterministic
shuffle, one pose-graph prior, held-out evaluation, and fixed-view visuals.

## Full indoor experiment

The known repeated-pose pairs for the reported indoor dataset were:

```bash
python3 src/reconstruct/scripts/compare_registration.py \
  "$HOME/dev/tree_scans/indoor_model_tree_2" \
  --profiles statistical \
  --closure-pairs 3:12,13:22,23:32 \
  --local-voxel-size-m 0.004 \
  --global-voxel-size-m 0.004
```

If request IDs change, omit `--closure-pairs`; the script attempts to detect
repeated TF poses automatically.

The default full run performs:

- TF-only fusion;
- chronological incremental TF+ICP;
- reverse incremental ICP;
- three deterministic shuffled incremental-ICP replays;
- robust relative-TF-initialized point-to-plane ICP edges;
- adjacent, TF-overlap, and repeated-pose closure constraints;
- loose, nominal, and strong TF-prior sweeps;
- held-out numerical evaluation;
- one-time fusion from optimized per-capture poses;
- fixed front, side, and top RGB/capture-ID views.

## Optional two-filter replication

Filter choice is not the primary registration variable, so one profile is the
cleanest first experiment. To test whether the conclusion is filter-specific:

```bash
python3 src/reconstruct/scripts/compare_registration.py \
  "$HOME/dev/tree_scans/indoor_model_tree_2" \
  --profiles current_radius statistical \
  --closure-pairs 3:12,13:22,23:32
```

## Output layout

Default output:

```text
<scan_dir>/registration_comparisons/<timestamp>/
```

For each filter profile:

| Output | Meaning |
| --- | --- |
| `registration_comparison.csv` | Summary for TF-only, incremental ICP, and every graph prior |
| `order_test/order_summary.csv` | Mean, 95th-percentile, and maximum pose changes caused only by replay order |
| `order_test/order_pose_differences.csv` | Per-capture order sensitivity |
| `pairwise_edges.csv` | Every attempted graph edge, overlap, metrics, correction, and acceptance reason |
| `heldout_edge_comparison.csv` | Pose and trimmed point-to-plane errors on edges excluded from optimization |
| `baselines/*/global_point_cloud.ply` | TF-only and incremental-ICP reconstructions |
| `pose_graph/tf_prior_*/global_point_cloud.ply` | Fuse-once graph reconstructions |
| `*/global_capture_id_cloud.ply` | Geometry colored by capture identity |
| `visuals/registration_rgb_fixed_views.png` | Identical RGB front/side/top views |
| `visuals/registration_capture_id_fixed_views.png` | Same views colored by capture |
| `visuals/incremental_order_*_fixed_views.png` | Visual replay-order comparison |
| `pose_graph/tf_prior_*/optimized_pose_graph.json` | Optimized Open3D graph |

Every run also writes manifests that preserve the source dataset, selected
capture attempts, effective settings, and transform conventions.

## Transform convention

`T_base_camera` maps camera-frame points into `base_link`.

A geometric edge from camera `i` to camera `j` stores
`T_camera_j_camera_i`.

Open3D graph node poses store `T_base_camera`. Node 0 is a fixed identity
`base_link` node. The absolute TF prior for capture `i` is therefore an edge
from node 0 to node `i` whose measurement is
`inverse(T_base_camera_i)`.

## Prior sweep

The presets are experimental weights, not measured calibration covariances:

| Preset | Translation sigma | Rotation sigma |
| --- | ---: | ---: |
| `loose` | 20 mm | 2.0° |
| `nominal` | 10 mm | 1.0° |
| `strong` | 5 mm | 0.5° |

Prefer a graph result only if it improves held-out consistency and repeated-pose
closure, reduces duplicate/thick surfaces, preserves thin structures, and does
not require implausibly large departures from calibrated TF.

## Reported indoor result

The chronological incremental baseline accepted all 32 captures and appeared
successful under conventional local metrics:

- mean fitness: approximately 0.927;
- mean RMSE: approximately 3.32 mm.

It nevertheless accumulated increasing departure from TF:

| Metric | Incremental TF+ICP |
| --- | ---: |
| Mean translation deviation | 5.30 mm |
| 95th-percentile translation deviation | 11.02 mm |
| Maximum translation deviation | 13.46 mm |
| Mean rotation deviation | 1.01° |
| Maximum rotation deviation | 1.94° |
| Translation-deviation slope | 0.264 mm/frame |
| Correlation with frame index | 0.762 |

Changing only replay order produced:

| Replay order | Accepted | Mean pose difference | Maximum pose difference | Mean rotation difference |
| --- | ---: | ---: | ---: | ---: |
| Reverse | 31/32 | 13.44 mm | 18.77 mm | 1.92° |
| Shuffled | 28/32 | 13.33 mm | 19.82 mm | 2.00° |

The nominal TF-anchored graph reduced mean deviation to approximately 1.99 mm
and 0.108°, reduced maximum deviation to 4.05 mm and 0.198°, and removed the
frame-wise translation trend.

It improved held-out pose residual and repeated-pose closure relative to
incremental ICP, while incremental ICP retained a slightly lower held-out
point-to-plane RMSE. The first pose-graph result was therefore a strong
drift-control result, not a definitive visual-quality winner.

## Visual evaluation

Full-canopy views can hide doubled leaves and branch surfaces. Use identical
base-frame crops for:

- a trunk section;
- one branch junction;
- two apples at different locations;
- representative thin leaves or leaf edges.

Use the same crop bounds, view, point size, and zoom for every method.

Thin slabs through a trunk, branch, or apple can reveal:

- duplicate shells;
- surface thickness;
- gaps;
- capture-to-capture displacement;
- whether different capture IDs form one surface or several layers.

Useful local metrics include cross-section thickness, fitted-plane/cylinder
residuals, nearest-neighbor spacing, and capture-to-capture spread.

## When TEASER++ is justified

TEASER++ addresses difficult pairwise alignment; it does not by itself solve
one-way accumulation in a sequential fusion architecture.

Inspect `pairwise_edges.csv`. A focused TEASER++ experiment becomes justified
when a specific, genuinely overlapping pair—especially a loop closure—fails
robust TF-initialized ICP despite:

1. verified UR and camera-to-tool calibration;
2. a reasonable relative-TF initialization;
3. sufficient overlap and point count;
4. plausible crop and filter settings.

TEASER++ could then propose that edge. The pose graph would still decide
whether the edge is globally consistent.

## Useful tuning

If no held-out overlap edges are selected:

```bash
--graph-min-aabb-overlap 0.02 --graph-extra-neighbors 5
```

If too many unrelated foliage pairs are attempted:

```bash
--graph-min-aabb-overlap 0.10 --graph-extra-neighbors 2
```

Do not relax the default 30 mm/5° graph-edge correction guards merely to make
more edges pass. Inspect failed request IDs, TF calibration, actual overlap,
and scene crop first.

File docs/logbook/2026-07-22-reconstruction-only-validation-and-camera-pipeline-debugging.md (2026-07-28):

# 2026-07-22 — Reconstruction-Only Validation and Camera Pipeline Debugging

## Day Objective

The primary goal for Wednesday was to validate the ROS 2 reconstruction pipeline independently of UR5e motion.

The planned validation sequence was:

1. Run only the RGB-D reconstruction node.
2. Receive synchronized color, aligned depth, and camera-intrinsics messages from the UR5e-mounted Jetson/RealSense camera.
3. create one colored point cloud.
4. place it in a consistent coordinate frame.
5. save the result as a PLY file.
6. inspect the cloud before enabling any robotic-arm motion.
7. only after the stationary pipeline works, proceed to controlled multi-view captures with the UR5e.

This separation was intentional. A stationary-camera test isolates RGB-D conversion, camera intrinsics, filtering, point-cloud generation, file output, and basic fusion from the additional complexity of arm motion, dynamic TF, hand–eye calibration, and trajectory execution.

---

## Progress Check and Reconstruction Strategy

Prepared a concise technical explanation for a progress meeting with Divyanth.

The reconstruction workflow was framed as two validation stages:

### Stage 1 — Stationary camera

Validate:

- synchronized RGB and aligned depth
- camera intrinsics
- depth scale
- color conversion
- point-cloud creation
- filtering
- PLY export
- repeated-frame behavior

Capturing two nearly identical stationary frames is only a weak ICP test because the point clouds should already overlap. It is mainly a pipeline sanity check.

### Stage 2 — Controlled camera motion

Once the stationary pipeline works:

- move the UR5e to a controlled second viewpoint
- use robot TF to place the new cloud approximately into a shared frame
- use ICP to refine the remaining alignment error
- inspect whether the fused result preserves trunk, branches, leaves, and apples without duplication or blur

The key architectural summary was:

> TF provides the pose prior; ICP provides the registration refinement.

ICP should not estimate the complete arm motion from scratch. The robot kinematics and TF tree should provide the approximate camera pose, while ICP corrects smaller residual errors caused by calibration, timing, depth noise, and imperfect transforms.

---

## Registration and ICP Review

Clarified the meaning of point-cloud registration:

> Registration is the process of finding the rigid rotation and translation that align one point cloud with another representation of the same physical scene.

The reconstruction node uses coarse-to-fine point-to-plane ICP.

The implementation confirms this through:

- voxel downsampling at multiple scales
- normal estimation using a hybrid KD-tree neighborhood
- `TransformationEstimationPointToPlane()`
- iterative convergence tests based on RMSE, fitness, and maximum iterations

### Point-to-plane ICP

For each source point, ICP finds a nearby target correspondence and minimizes the source point’s distance to the target surface’s local tangent plane.

This requires surface normals, which are estimated from neighboring points.

Point-to-plane ICP is generally more suitable than basic point-to-point ICP for RGB-D surface reconstruction because it uses local surface orientation and often converges faster when the initial estimate is already close.

---

## Multiscale Registration Interpretation

Confirmed that the reconstruction node runs the scales in this order:

`SN3 → SN2 → SN1 → SN0`

This is a coarse-to-fine sequence.

| Scale | Voxel size | Correspondence distance | Maximum iterations | Role |
|---|---:|---:|---:|---|
| `SN3` | 0.05 m | 0.05 m | 50 | Coarse 5 cm alignment |
| `SN2` | 0.02 m | 0.03 m | 30 | Intermediate refinement |
| `SN1` | 0.01 m | 0.018 m | 20 | Fine 1 cm refinement |
| `SN0` | 0.0 m | 0.012 m | 15 | Full-resolution final refinement |

`SN0` having `voxel_size_m: 0.0` does not mean zero resolution. It is used as a sentinel meaning:

> Do not voxel-downsample; use the original point cloud.

The transform estimated at each scale is passed as the initial guess for the next finer scale.

The current ROS 2 thresholds are somewhat more permissive than the original ROS 1 values, especially at intermediate and fine scales. This was intended to reduce unnecessary rejection during initial testing but may later need tightening after real reconstruction quality is measured.

---

## ROS 2 Preflight Results

Ran the live ROS 2 interface checks.

### ROS domain behavior

The UR5e controller and joint-state interfaces appeared only when using:

`ROS_DOMAIN_ID=26`

Without the correct domain, only a smaller camera-oriented ROS graph was visible.

This explained why topics and actions seemed to disappear between terminals. Every terminal used for testing must share the same ROS domain and sourced workspace.

### UR5e action servers discovered

The following `FollowJointTrajectory` actions were available when the UR stack was online:

- `/joint_trajectory_controller/follow_joint_trajectory`
- `/passthrough_trajectory_controller/follow_joint_trajectory`
- `/scaled_joint_trajectory_controller/follow_joint_trajectory`

### Controller state

`ros2 control list_controllers` showed:

- `joint_state_broadcaster` active
- `io_and_status_controller` active
- `speed_scaling_state_broadcaster` active
- `force_torque_sensor_broadcaster` active
- `tcp_pose_broadcaster` active
- `scaled_joint_trajectory_controller` inactive
- `joint_trajectory_controller` inactive

For later physical motion, the scaled controller is the likely target, but it must first be activated and verified through the UR external-control startup sequence.

### Correct joint-state topic

The active UR5e joint-state topic is:

`/joint_states`

The earlier configured topic, `/platform/joint_states`, was not present in the current arm-only ROS graph.

### Camera topics confirmed

The reconstruction inputs were active:

- `/sensors/camera_jetson/color/image_raw`
- `/sensors/camera_jetson/aligned_depth_to_color/image_raw`
- `/sensors/camera_jetson/aligned_depth_to_color/camera_info`

Observed image rates were approximately 16–17 Hz after startup.

The aligned-depth camera information reported:

- frame: `camera_jetson_color_optical_frame`
- resolution: 640 × 480
- focal lengths near 605.6 pixels
- principal point near `(323.95, 247.77)`
- `plumb_bob` distortion model with zero reported coefficients

### Time configuration

No `/clock` topic was present during the physical-camera test. The reconstruction launch was therefore changed to:

`use_sim_time:=false`

The camera timestamps were already wall-clock timestamps.

---

## TF Validation

When the UR stack was active, a transform from `base_link` to a camera optical frame could be resolved after an initial TF discovery delay.

Later in the day, the robot appeared to be powered off or its ROS driver was no longer active. At that point, the available ROS graph contained the camera topics and `/tf_static`, but no:

- `/tf`
- `/joint_states`
- controller topics
- active robot-state TF tree

The reconstruction node then correctly reported:

`TF unavailable: base_link <- camera_jetson_color_optical_frame`

This confirmed that the RGB-D synchronizer was functioning and that processing had reached the TF lookup stage. The remaining failure was specifically the absence of the robot-side `base_link` frame.

---

## Camera-Only Reconstruction Mode

To continue testing without the robot, the reconstruction target was changed from `base_link` to the camera’s own optical frame:

`target_frame: camera_jetson_color_optical_frame`

The camera frame override was also set or allowed to resolve to the same frame.

An identity-transform case was added to `_lookup_transform_matrix()`:

`if target_frame == source_frame: return np.eye(4, dtype=np.float64)`

This allows the point cloud to remain in camera optical coordinates without querying TF.

In camera optical coordinates:

- positive X points right
- positive Y points down
- positive Z points forward

This mode can validate point-cloud creation and PLY output, but it does not validate:

- robot kinematics
- dynamic TF
- hand–eye calibration
- camera motion
- multi-view placement in `base_link`

---

## Reconstruction-Only Launch and Capture Trigger

Launched the node with motion disabled:

`ros2 launch reconstruct scan_tree.launch.py execute_motion:=false use_sim_time:=false`

The node started successfully and reported:

- capture topic: `/capture_alert`
- configured Jetson RGB-D inputs
- output path: `~/tree_scans/indoor_model_tree/global_point_cloud.ply`

Manual capture requests were sent using:

`ros2 topic pub --once /capture_alert std_msgs/msg/Bool "{data: true}"`

The node received and queued the capture requests correctly.

Initially, the queued count increased without producing `/capture_done` or a PLY. Once the camera and TF conditions changed, the callback progressed further and exposed the next runtime issue.

This confirmed that the trigger path itself was functional.

---

## RGB-D Conversion Failure

After enabling camera-only operation, the callback successfully reached RGB-D point-cloud creation but Open3D raised:

`Image can only be initialized from buffer of uint8, uint16, or float!`

The failure occurred at:

`o3d.geometry.Image(depth_array)`

### Depth diagnostics

Additional logging confirmed:

- encoding: `16UC1`
- shape: 480 × 640
- dtype: `uint16`
- native little-endian representation: `<u2`
- contiguous memory: true
- depth scale: `1000.0`

These values are conceptually valid for Open3D RGB-D input.

The depth conversion code was updated to:

- determine units independently from dtype normalization
- preserve `16UC1` as `uint16`
- preserve `32FC1` as `float32`
- reject unsupported or negative integer depth values
- ensure native byte order
- ensure contiguous arrays
- log encoding, dtype, shape, and scale

Despite this normalization, Open3D continued to reject the valid `uint16` array.

---

## Python Environment Warning

Every launch produced a SciPy warning:

`SciPy requires NumPy < 1.25.0, but NumPy 1.26.4 is installed`

The observed environment included:

- NumPy 1.26.4
- SciPy 1.8.0
- Open3D 0.19.0

The Open3D image-constructor failure may be related to binary incompatibility or mixed system/pip Python packages, although this was not proven conclusively during the day.

The warning itself did not prevent the ROS node from starting, but the Python environment should be made internally consistent before relying on it for repeatable experiments.

---

## Proposed Direct NumPy Back-Projection

Because Open3D rejected an otherwise valid depth array, a fallback was designed to bypass `o3d.geometry.Image` and `RGBDImage.create_from_color_and_depth()`.

The proposed replacement directly back-projects each valid depth pixel using the pinhole-camera equations:

`X = (u - cx) Z / fx`

`Y = (v - cy) Z / fy`

`Z = depth`

The matching RGB values are normalized to `[0, 1]`, and the resulting arrays are assigned directly to:

- `o3d.utility.Vector3dVector` for points
- `o3d.utility.Vector3dVector` for colors

This would preserve the remainder of the pipeline:

- TF or identity placement
- filtering
- multiscale point-to-plane ICP
- global fusion
- ROS `PointCloud2` publication
- PLY output

This fallback was proposed but had not yet been implemented and validated by the end of the recorded work.

---

## Parameter Concepts Reviewed

Reviewed the main registration and filtering parameters in preparation for later tuning.

### Voxel size

A voxel is a 3D grid cell. Voxel downsampling replaces all points within each cell with a representative point.

Larger voxels:

- reduce point count
- increase speed
- suppress fine detail
- broaden the ICP convergence basin

Smaller voxels:

- preserve detail
- increase runtime and memory use
- require a better initial pose

### Maximum correspondence distance

This is the largest source-to-target separation allowed when forming ICP matches.

If too small:

- valid overlap may be ignored
- fitness may become low
- registration may fail

If too large:

- unrelated leaves or branches may be matched
- ICP may converge to an incorrect alignment

### Convergence criteria

The Open3D ICP loop stops when one of these occurs:

- relative RMSE improvement becomes sufficiently small
- relative fitness improvement becomes sufficiently small
- maximum iterations are reached

These stopping thresholds are different from the final acceptance thresholds.

### Fitness and RMSE acceptance

Fitness is the fraction of source points that obtain valid target correspondences.

Higher fitness is generally better.

Inlier RMSE measures the geometric error among accepted correspondences.

Lower RMSE is generally better.

A completed ICP result can converge internally and still be rejected if its final fitness or RMSE fails the configured acceptance thresholds.

### Outlier rejection

The node uses radius-outlier removal.

A point survives only if it has at least a configured number of neighboring points within a configured radius.

This removes isolated depth noise but can also erase thin leaves, apple edges, and small branches if configured too aggressively.

### Normal estimation

Point-to-plane ICP requires local surface normals.

Normals are estimated from neighboring points using a hybrid KD-tree search with:

- a search radius linked to voxel size and correspondence distance
- a maximum of 40 neighbors

The neighborhood must be large enough to estimate a stable surface direction but not so large that it averages across separate leaves, branches, or curved structures.

---

## End-of-Day Status

By the end of Wednesday, July 22:

- The ROS 2 workspace built successfully.
- The reconstruction node launched successfully with motion disabled.
- The correct Jetson RGB-D topics were configured.
- `ROS_DOMAIN_ID=26` was identified as necessary for seeing the UR5e ROS graph.
- The correct arm joint-state topic was identified as `/joint_states`.
- Three trajectory action servers were discovered.
- The relevant trajectory controllers were present but inactive.
- The camera streams and intrinsics were verified.
- Physical-camera testing used `use_sim_time:=false`.
- The reconstruction trigger path worked.
- The synchronized RGB-D callback worked when the camera streams were available.
- TF placement into `base_link` worked only while the robot-side TF tree was active.
- A camera-only identity-frame mode was added to permit testing with the robot off.
- The pipeline advanced through image synchronization, frame selection, TF handling, and depth conversion.
- Depth input was confirmed as valid `16UC1`, 640 × 480, `uint16`, with a 1000.0 scale.
- Open3D still rejected the normalized depth array during `geometry.Image` construction.
- No successful PLY was produced during the recorded work.
- No UR5e motion was attempted.
- A direct NumPy pinhole back-projection was prepared as the next workaround.
- The mixed NumPy/SciPy/Open3D environment remained a probable technical risk.

---

## Next Steps

1. Replace or temporarily bypass Open3D’s RGB-D image constructor using direct NumPy back-projection.
2. rebuild and confirm that one camera-only capture produces a colored Open3D point cloud.
3. verify `/capture_done` publication.
4. verify creation of `global_point_cloud.ply`.
5. inspect the first cloud in Open3D, CloudCompare, or RViz for:
   - orientation
   - scale
   - color correctness
   - depth cutoff
   - missing regions
   - near-depth saturation
   - noise and isolated points
6. capture several stationary frames and verify that fusion does not blur or duplicate surfaces.
7. restore `target_frame: base_link` when the UR5e TF tree is online.
8. activate and verify the selected trajectory controller.
9. run a very small supervised move–settle–capture sequence.
10. only after a successful multi-view test, tune voxel, outlier, correspondence, fitness, RMSE, and depth parameters for leaves, branches, and apples.

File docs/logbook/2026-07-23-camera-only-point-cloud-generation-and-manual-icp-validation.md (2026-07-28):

# 2026-07-23 — Camera-Only Point Cloud Generation and Manual ICP Validation

## Day Objective

The primary goal for Thursday was to move beyond the previous day's RGB-D conversion failure and validate the complete camera-only point-cloud reconstruction pipeline.

The focus was:

1. confirm the Python/Open3D environment;
2. replace the failing Open3D RGB-D image conversion path;
3. generate a colored point cloud from the Jetson-mounted Intel RealSense camera;
4. save the result as a global PLY;
5. test repeated captures and coarse-to-fine ICP using small manual camera movements;
6. inspect reconstruction quality and identify the next tuning priorities.

No UR5e motion was attempted because the end-effector camera mount was broken and being reprinted.

---

## Python Environment Verification

The active Python environment was confirmed as:

- NumPy 1.26.4
- SciPy 1.8.0
- Open3D 0.19.0
- Open3D installed under `~/.local/lib/python3.10/site-packages`

SciPy continued to warn that it expected NumPy below 1.25.0. The environment is therefore internally inconsistent, but the warning did not prevent the node from running.

The earlier Open3D failure occurred even though the incoming depth image had valid properties:

- encoding: `16UC1`
- resolution: 640 × 480
- dtype: `uint16`
- little-endian
- contiguous memory
- depth scale: 1000.0

---

## Direct NumPy RGB-D Back-Projection

The failing Open3D path based on `o3d.geometry.Image` and `RGBDImage.create_from_color_and_depth()` was bypassed.

The replacement directly back-projects each valid depth pixel into 3D using the camera intrinsics:

- `X = (u - cx) Z / fx`
- `Y = (v - cy) Z / fy`
- `Z = depth`

The corresponding RGB pixel is assigned to each generated 3D point.

This preserved the rest of the existing pipeline:

- camera-frame or TF placement;
- local filtering;
- multiscale point-to-plane ICP;
- global fusion;
- ROS `PointCloud2` publication;
- per-frame image/depth/metadata export;
- continuously updated global PLY output.

This change resolved the RGB-D point-cloud creation blocker.

---

## First Successful End-to-End Capture

The reconstruction node was launched with motion disabled and wall-clock time:

`ros2 launch reconstruct scan_tree.launch.py execute_motion:=false use_sim_time:=false`

The first successful capture produced:

- accepted first frame;
- camera-only identity transform;
- approximately 18,479 fused points;
- reconstruction time of approximately 167 ms;
- a valid `global_point_cloud.ply`;
- a `/capture_done` response.

A previous test had produced only 58 points because the camera was unintentionally facing the floor. Once the camera was aimed at the tree, captures produced tens of thousands of points.

This confirmed the complete path:

`RGB + aligned depth + intrinsics → colored point cloud → filtering → fusion → PLY`

---

## Capture and File Behavior

The node maintains one in-memory global point cloud and continuously rewrites one file:

`~/tree_scans/indoor_model_tree/global_point_cloud.ply`

Accepted captures are transformed, optionally corrected by ICP, and added to `global_pc`.

Rejected ICP captures do not modify the global point cloud, although the existing global PLY may still be rewritten unchanged.

For captures that process far enough to reach `_fuse_frame()`, the node saves per-frame files regardless of final ICP acceptance:

- color image;
- depth image;
- metadata JSON.

The metadata records whether the frame was accepted and includes:

- ICP fitness;
- ICP RMSE;
- target and camera frames;
- camera intrinsics;
- TF transform;
- ICP correction.

Frames that fail before this stage, such as missing TF, failed image conversion, or zero generated points, are not saved.

---

## Near-Depth Behavior

Objects placed very close to the camera were missing from both the aligned depth image and resulting PLY, even after setting:

- minimum depth to 0.0 m;
- maximum depth to 5.0 m.

Backing the camera away caused the object to appear correctly.

The camera driver was inspected by SSHing into the Warthog computer and switching to `ROS_DOMAIN_ID=26`.

The RealSense node was:

`/sensors/camera_jetson`

Relevant driver settings included:

- `align_depth.enable: true`
- `depth_module.depth_format: Z16`
- `depth_module.depth_profile: 640,480,30`
- `clip_distance: -2.0`
- emitter enabled
- auto exposure enabled
- depth and color enabled
- camera TF publication enabled

Because there was no positive software clipping distance configured, the close-range gap was judged more likely to come from the physical stereo minimum range, invalid disparity at close distance, or aligned-depth occlusion behavior.

Since moving the camera farther back was an effective workaround, near-depth tuning was deprioritized.

---

## Manual Multi-View Scan

Because the printed camera mount was unavailable, the UR5e scan was approximated manually.

A repeated `/capture_alert` loop was used while the camera was moved by hand in small increments.

The intended movement strategy was:

- approximately 2–5 cm between captures;
- minimal rotation;
- high overlap between consecutive views;
- hold the camera still during each capture;
- stop with `Ctrl+C`.

This was a harder test than the eventual robot scan because camera-only mode supplied no motion prior. Every capture entered in the same camera frame, so ICP had to estimate the complete relative movement.

---

## Manual ICP Results

Seven captures were attempted.

Representative accepted results:

| Capture | Fitness | RMSE | Global points |
|---|---:|---:|---:|
| 1 | TF only | — | 18,479 |
| 2 | 0.831 | 5.8 mm | 27,776 |
| 3 | 0.823 | 5.1 mm | 35,576 |
| 6 | 0.922 | 4.5 mm | 44,734 |
| 7 | 0.824 | 4.4 mm | 55,044 |

Captures 4 and 5 were rejected at `SN3`:

- capture 4: fitness 0.509, RMSE 29.1 mm;
- capture 5: fitness 0.474, RMSE 30.4 mm.

Both exceeded the coarse-scale RMSE threshold of 25 mm.

The later recovery at capture 6 showed that the global map remained valid after rejected frames and that a sufficiently overlapping viewpoint could still register successfully.

The accepted fitness values around 0.82–0.92 and RMSE values around 4–6 mm indicate that coarse-to-fine point-to-plane ICP was functioning correctly under small manual viewpoint changes.

---

## Coarse-to-Fine ICP Confirmation

Every post-initial capture runs the full registration sequence:

`SN3 → SN2 → SN1 → SN0`

There is no separate fine scan that must be triggered later.

The final `SN0` stage uses no additional scale-specific voxel downsampling, but the input cloud has already been filtered using the configured local voxel size.

Therefore, `SN0` is full resolution relative to the filtered frame, not necessarily full raw camera resolution.

The global point cloud is also downsampled after fusion using the configured global voxel size.

---

## Initial Reconstruction Quality

The resulting point cloud was recognizable and substantially better than the earlier single-frame tests. The tree, canopy, and several apples could be identified.

However, the cloud remained visually limited:

- grainy point-based appearance;
- significant room and whiteboard background geometry;
- floating clusters;
- incomplete side and rear coverage;
- poor appearance from oblique viewpoints;
- dull color;
- incomplete thin branches, leaves, and apple surfaces.

The PLY is currently a colored point cloud, not a triangle mesh. It therefore lacks:

- continuous surfaces;
- watertight geometry;
- texture maps;
- simulator-ready collision geometry.

A later processing stage will be required for cropping, denoising, surface reconstruction, mesh cleanup, and simulation import.

---

## Interpretation of the Current Quality

Good ICP metrics do not guarantee a simulator-ready reconstruction.

The current limitations are primarily caused by:

- limited viewpoint coverage;
- manual camera motion;
- the tree being observed mainly from the front;
- background geometry being included;
- RealSense depth noise;
- incomplete sensing of thin and reflective structures;
- global voxel downsampling;
- lack of post-processing or meshing.

The poor side view is expected because frontal captures mainly create a partial front-facing shell. ICP can align observed surfaces but cannot reconstruct unseen sides or the rear of the tree.

A shallow arc around the tree will be more valuable for 3D completeness than repeatedly capturing nearly identical frontal images.

---

## Parameter Tuning Priorities

### Depth cropping

The most important immediate improvement is to reduce the retained depth range around the tree.

A 5 m maximum includes much of the laboratory and allows background geometry to influence both appearance and registration.

A target-relative range such as approximately 0.35–2.0 m was suggested as a starting point, depending on measured camera-to-tree distance.

### Voxel resolution

The current filtered and global clouds use millimeter-scale voxels.

A finer experimental configuration was suggested:

- local voxel size: approximately 4 mm;
- global voxel size: approximately 3 mm.

This may preserve more apple, branch, and leaf detail, at the cost of higher point counts and runtime.

### Outlier rejection

Disabling outlier rejection was identified as a useful comparison test, but it was expected to retain more floating depth noise.

A less aggressive radius filter may better preserve thin structures:

- radius around 15 mm;
- minimum neighbors around 4.

The goal is not simply to maximize point count, but to preserve true thin geometry without keeping isolated noise.

### ICP thresholds

The ICP thresholds were not loosened.

Captures 4 and 5 likely represented poor overlap or excessive manual movement, and accepting them could introduce duplicated or blurred geometry.

The current thresholds appeared to reject bad views while preserving later recovery.

### Final cleanup

Statistical outlier removal was identified as a possible final post-processing step after the complete scan rather than after every capture.

A tight spatial crop around the tree is expected to improve visual quality more than aggressive ICP changes.

---

## Color Quality

The dull point-cloud color was traced primarily to the source RGB frames and viewing conditions.

The frames showed:

- strong backlighting;
- dark foliage;
- low contrast;
- softness and occasional motion blur;
- bright room background.

There was no obvious RGB/BGR channel reversal because green foliage and warm apple colors remained plausible.

Potential later improvements include:

- keeping the camera stationary during capture;
- reducing backlighting;
- adjusting RealSense exposure, gain, white balance, sharpness, or saturation;
- changing point-viewer rendering settings;
- delaying color enhancement until geometry is validated.

---

## End-of-Day Status

By the end of Thursday, July 23:

- the direct NumPy back-projection workaround was implemented successfully;
- camera-only RGB-D point-cloud generation worked end to end;
- valid colored PLY files were generated;
- `/capture_done` worked;
- single captures produced tens of thousands of points;
- repeated captures updated one global PLY;
- per-frame color, depth, and metadata files were saved;
- manual multi-view captures successfully exercised coarse-to-fine point-to-plane ICP;
- accepted registrations achieved fitness around 0.82–0.92 and RMSE around 4–6 mm;
- poor-overlap frames were rejected at the coarse scale;
- the global cloud remained valid after rejected frames;
- the tree and apples were recognizable;
- background clutter, limited coverage, depth noise, and point-cloud sparsity remained;
- no UR5e motion was attempted because the camera mount was being reprinted;
- the result was not yet a simulator-ready mesh.

---

## Next Steps

1. rerun the scan with a tighter tree-centered depth range;
2. compare outlier rejection enabled versus disabled;
3. test finer local and global voxel sizes;
4. add point-count and depth-range diagnostics for controlled comparisons;
5. perform a denser manual or robotic scan over a shallow horizontal and vertical arc;
6. restore `target_frame: base_link` when the robot and camera TF chain are online;
7. verify camera-to-tool extrinsic calibration before relying on robot motion;
8. run the move–settle–capture workflow using the UR5e;
9. crop the fused cloud tightly around the tree;
10. evaluate apples, leaves, branches, and trunk in fixed close-up views and cross-sections;
11. add final statistical denoising;
12. investigate TSDF, Poisson, or ball-pivoting reconstruction for conversion into a simulation-usable mesh.

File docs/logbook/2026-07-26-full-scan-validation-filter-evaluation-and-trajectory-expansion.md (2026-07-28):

# 2026-07-26 — Full-Scan Validation, Filter Evaluation, and Trajectory Expansion

## Day Objective

The primary goal for Sunday was to move beyond the isolated capture-timeout incident and evaluate the reconstruction system as a complete scanning pipeline.

The work focused on:

1. confirming that the complete 32-step UR5e trajectory could run reliably with one capture at every settled pose;
2. evaluating the resulting tree point cloud quantitatively rather than relying only on visual judgment;
3. separating registration quality, point density, voxel resolution, and outlier filtering as distinct reconstruction variables;
4. identifying why an attempted voxel-size comparison initially produced identical results;
5. determining whether missing leaves or branches were caused by filtering or by acquisition coverage;
6. expanding the trajectory to include an additional high row and stronger oblique views;
7. preparing the revised trajectory generator for a cautious hardware test.

These notes begin after the earlier one-off timeout, once the full 32-step run was reported to work correctly.

---

## Full 32-Step Integrated Scan

The complete recorded trajectory was replayed successfully with the reconstruction node connected.

For every trajectory step, the system followed the intended sequence:

`move → settle for 1000 ms → request capture → wait for result → continue`

All 32 capture requests were accepted. The later portion of the scan included:

- Row 1 completion through captures 20–22;
- movement to Row 2 center at capture 23;
- left, right, and neutral-gaze observations across Row 2;
- a direct 0.30 m lateral move between the left and right positions;
- final return to Row 2 center at capture 32;
- automatic return of the arm to the home pose.

The replay ended with:

`Scanning trajectory replay completed successfully.`

This demonstrated that the earlier delayed capture was likely a one-off camera or synchronization event rather than a persistent failure in the trajectory–reconstruction interface.

---
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

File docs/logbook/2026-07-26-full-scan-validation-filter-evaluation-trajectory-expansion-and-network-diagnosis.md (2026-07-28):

# 2026-07-26 — Full-Scan Validation, Filter Evaluation, and Trajectory Expansion

## Day Objective

The primary goal for Sunday was to move beyond the isolated capture-timeout incident and evaluate the reconstruction system as a complete scanning pipeline.

The work focused on:

1. confirming that the complete 32-step UR5e trajectory could run reliably with one capture at every settled pose;
2. evaluating the resulting tree point cloud quantitatively rather than relying only on visual judgment;
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

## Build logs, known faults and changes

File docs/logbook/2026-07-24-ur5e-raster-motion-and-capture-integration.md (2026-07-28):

# 2026-07-24 — UR5e Raster Motion and Capture Integration

## Day Objective

The primary goal for Friday was to move beyond camera-only reconstruction and begin integrating the real UR5e motion stack with the RGB-D capture pipeline.

The work focused on:

1. understanding Dawood's raster-scan implementation and its relationship to the reconstruction package;
2. preparing the ROS 2 MoveIt and Universal Robots dependencies;
3. launching the UR5e driver and trajectory controllers;
4. generating and replaying a recorded scan trajectory;
5. validating the first trajectory segments cautiously on hardware;
6. diagnosing an unsafe trajectory-controller rejection;
7. connecting each settled robot pose to the reconstruction node's capture request/result interface.

---

## Workspace and Package Organization

Two separate workspaces were in use and needed to remain conceptually distinct:

- `~/dev/cornell-warthog-sim`
  - contains the migrated `reconstruct` package;
  - contains `pointcloud_processing.py`, the RGB-D reconstruction node;
  - contains the reconstruction configuration in `src/reconstruct/config/params.yaml`.

- `~/dev/dawood_tree_scanning_ur5e`
  - contains Dawood's `arm_scan_motion` package;
  - contains the MoveIt configuration and UR5e bringup launch files;
  - contains the raster trajectory generator and the `scanning_trajectory` replay executable;
  - contains `recorded_scan_trajectory.json`.

This distinction became important after an initial search looked for the trajectory path under `cornell-warthog-sim`, even though `arm_scan_motion` and its JSON lived in Dawood's workspace.

---

## Motion Package and Raster-Scan Design

Dawood's motion package generates a structured scan around a manually selected starting pose.

The intended motion is a raster, or snake, pattern:

- move across one row;
- step vertically to the next row;
- reverse horizontal direction;
- continue alternating until all rows are covered.

The scan parameters considered included:

- four rows;
- 0.15 m row spacing;
- 0.15 m lateral offset;
- 15-degree camera look angle;
- velocity scaling of 0.05;
- acceleration scaling of 0.05.

The planned workflow separated trajectory validation from recording:

- use `record_trajectory:=false` for a cautious motion-only validation;
- use `record_trajectory:=true` only after the scan geometry was confirmed;
- save the resulting trajectory to an explicit JSON path;
- increase `max_steps` only as more of the sequence was validated.

A 42-step trajectory was considered for the complete four-row scan. The additional steps were intended to increase view coverage rather than change the underlying raster geometry.

The scan axes are defined in the end-effector frame. Because the RealSense mount orientation can rotate the camera relative to the tool, `scan_axis_u_ee` and `scan_axis_v_ee` must match the actual mount rather than being assumed from the nominal tool axes.

---

## ROS 2 and MoveIt Dependency Setup

The Dawood workspace initially failed to build or launch because required ROS 2 packages were missing.

Observed issues included:

- missing `moveit_ros_planning_interface` during `colcon build`;
- missing `realsense2_description`;
- missing `ur_robot_driver`.

The environment was sourced in this order:

1. `/opt/ros/humble/setup.bash`;
2. `~/dev/cornell-warthog-sim/install/setup.bash`;
3. `~/dev/dawood_tree_scanning_ur5e/install/setup.bash`, as appropriate for the command.

`realsense2_description` was later found under `/opt/ros/humble`. The UR driver and MoveIt packages also had to be available before the hardware bringup could succeed.

Old ROS processes were treated as a possible source of duplicate nodes, stale controllers, or launch conflicts. Only one UR driver and one `/controller_manager` should be active.

---

## UR5e Bringup and Controller State

The real robot driver must remain running while a separate terminal executes the trajectory.

The intended arrangement became:

1. launch `arm_scan_motion bringup.launch.py` with `use_sim_time:=false`;
2. leave that terminal running;
3. verify the desired trajectory controller is active;
4. run the trajectory executable from another terminal;
5. run the reconstruction node from a third terminal when capture is enabled.

The controller manager exposed several possible trajectory controllers:

- `scaled_joint_trajectory_controller`;
- `joint_trajectory_controller`;
- `passthrough_trajectory_controller`.

At one diagnostic point, all three were loaded but inactive, while state and status broadcasters were active. The existence of a `follow_joint_trajectory` action name did not by itself mean the corresponding controller could execute motion.

The replay executable targeted `joint_trajectory_controller`. Therefore, that controller needed to be active before testing.

Both of the checked time parameters were correctly set to wall-clock time:

- `/controller_manager use_sim_time = False`;
- `/joint_trajectory_controller use_sim_time = False`.

For hardware operation, simulation time must remain disabled.

---

## Recorded Trajectory File

The motion generator produced:

`~/dev/dawood_tree_scanning_ur5e/recorded_scan_trajectory.json`

The file contained:

- six UR5e joint names;
- a sequence of named trajectory segments;
- per-point positions;
- per-point velocities and accelerations;
- `time_from_start_sec` values;
- per-segment pause information.

The replay node supports the `trajectory_input_path` parameter. An absolute path was preferred so the executable could not silently load a different relative JSON file.

---

## Initial Hardware Replay and Safety Fault

The first single-step test corresponded to `Home Base`. It was not a meaningful motion test because the segment contained only one point at `t=0`, already approximately equal to the robot's current home pose.

The first real movement occurred in step 2, `Initial Look Down`.

During that test, the UR controller reported a jump from approximately:

- initial joint value: `-1.25007` rad;
- commanded value: `-1.20133` rad;
- elapsed controller time: approximately 0.002 s.

The controller rejected the command rather than executing the apparent instantaneous jump. Testing beyond step 1 was stopped while the trajectory was inspected offline.

This was treated as a safety-critical execution problem, not as evidence that the intended raster geometry was wrong.

---

## Offline JSON Validation

The boundary between steps 1 and 2 was inspected with `jq`.

Step 1 ended at:

- one point;
- `time_from_start_sec = 0`;
- joint positions approximately `[-0.0599549, -1.25007, 2.29995, 1.57011, -1.56997, -1.56994]`.

Step 2 contained ten points:

- first point at `t=0`;
- second point at approximately `t=0.0959` s;
- final point at approximately `t=0.8774` s.

The largest position difference between the end of step 1 and beginning of step 2 was only about `3e-5` rad. The segment boundary was therefore effectively continuous.

Within step 2:

- samples were generally spaced by approximately 0.10–0.11 s;
- the relevant joint moved gradually from `-1.25008` to `-1.20133` rad;
- the final point duplicated the previous point after another approximately 40 ms;
- total intended duration was approximately 0.877 s.

This cleared the JSON and Dawood's planned spatial path. The file did not command the final pose after 2 ms.

---

## Replay-Code Diagnosis

An early hypothesis was that the replay code might overwrite trajectory points or send each point as a separate action. Inspection of `scanning_trajectory.cpp` disproved that theory.

The code:

- appended all recorded points to one `FollowJointTrajectory` goal;
- preserved positions;
- preserved velocities and accelerations;
- preserved each recorded `time_from_start`.

The more plausible issue was that every segment began with its first point at exactly `time_from_start = 0`, while the goal header also implied an immediate start. By the time the controller processed the goal on its next update, the first sample was already at or behind the start boundary.

The replay path also differed from executing the original MoveIt plan directly. A trajectory that was valid in the MoveIt planning context was being serialized and then sent later as an independent controller goal.

---

## Positive Trajectory Lead-In

A 0.25-second positive lead-in was added to every replayed point:

`pt.time_from_start = rclcpp::Duration::from_seconds(trajectory_lead_in_sec + rpt.time_from_start_sec);`

The same lead-in was added to the computed segment duration used for waiting on the result:

`seg_duration = trajectory_lead_in_sec + seg.points.back().time_from_start_sec;`

The constant was declared once before the segment loop:

`constexpr double trajectory_lead_in_sec = 0.25;`

This changes step 2 from a trajectory beginning at `t=0` and ending at approximately `t=0.877` s to one beginning at `t=0.25` s and ending at approximately `t=1.127` s.

The purpose is to give the controller a valid future first point rather than an already-expired zero-time point.

Increasing the inter-segment `pause_ms` would not solve this issue because pausing before sending a goal does not change the goal's internal trajectory timestamps.

---

## Motion-Only Validation

The replay node enables reconstruction captures by default.

An initial `max_steps:=1` run loaded the trajectory successfully but exited after 15 seconds because no capture pipeline was connected:

`Capture pipeline was not connected within 15.0 s. Start the reconstructor first or set capture_enabled:=false.`

For motion-only validation, capture therefore needed to be disabled explicitly with:

`-p capture_enabled:=false`

This failure was unrelated to the UR controller or motion. It confirmed that the replay executable checks for the reconstruction request/result interface before beginning a capture-enabled run.

---

## Reconstruction Integration

The reconstruction node was launched from `cornell-warthog-sim` with wall-clock time:

`ros2 launch reconstruct scan_tree.launch.py params_file:="$HOME/dev/cornell-warthog-sim/src/reconstruct/config/params.yaml" use_sim_time:=false`

It reported:

- readiness on `/tree_scan/capture_request`;
- RGB-D topics from `/sensors/camera_jetson`;
- output to `~/dev/tree_scans/indoor_model_tree_1/global_point_cloud.ply`.

The trajectory node connected successfully to:

- `/tree_scan/capture_request`;
- `/tree_scan/capture_result`.

The intended integrated cycle was:

`move → wait for robot result → settle → request capture → wait for capture result → continue`

---

## Capture Timeout

A five-step replay was started with the reconstruction node connected.

Step 1 reached the home pose and requested capture 1 after a 1000 ms settle time. The trajectory node then timed out after 15 seconds and aborted.

The reconstructor log showed:

- capture request queued at approximately `18:54:37.241`;
- trajectory timeout at approximately `18:54:52.240`;
- scan-complete message received immediately after the abort;
- reconstructor began waiting for five new synchronized RGB-D frames at approximately `18:55:03.260`;
- capture accepted at approximately `18:55:03.725`.

The capture therefore succeeded, but about 11 seconds after the trajectory node had already timed out.

Once synchronized frames became available, burst collection and point-cloud processing took less than half a second. Most of the delay occurred before processing while waiting for new synchronized RGB, aligned depth, and camera-info messages.

The accepted first capture produced:

- first-frame/TF-only acceptance;
- approximately 81.6% valid median-depth pixels;
- 5,378 global points;
- approximately 229 ms reported processing time.

---

## Interpretation of the Timeout

The request/result communication worked correctly. The immediate problem was delayed RGB-D synchronization or intermittent camera delivery, not point-cloud computation.

The replay timeout of 15 seconds was shorter than the approximately 26-second delay between the capture request and the reconstructor beginning its burst.

The following camera streams were identified for rate and timestamp checks:

- `/sensors/camera_jetson/color/image_raw`;
- `/sensors/camera_jetson/aligned_depth_to_color/image_raw`;
- `/sensors/camera_jetson/aligned_depth_to_color/camera_info`.

Increasing the capture timeout to at least 35 seconds could permit testing to continue, but would only mask the underlying camera or synchronization delay.

Another lifecycle issue was exposed: after the trajectory node aborted, it published scan completion while the reconstructor still had a pending request. The reconstructor announced the final PLY and then later processed the queued capture.

The completion behavior should eventually be made consistent by either:

- cancelling pending captures when a scan is aborted or completed; or
- delaying finalization until the pending capture queue is empty.

Otherwise, the file described as final can still be modified by a late capture.

---

## Operational Safety Notes

The following conditions were established before future motion tests:

- use only one UR driver and one controller manager;
- keep `use_sim_time:=false` for the hardware driver, controller manager, trajectory controller, and reconstruction node;
- verify the controller targeted by the replay code is active;
- keep the pendant's External Control program running and the robot enabled;
- begin with `max_steps:=1`;
- enable additional steps only after the previous step behaves correctly;
- keep the pendant emergency stop immediately accessible;
- do not assume action-server visibility means the controller is active;
- do not use a longer pause as a substitute for valid internal trajectory timing;
- use absolute paths for the trajectory JSON and parameter files.

---

## End-of-Day Status

By the end of Friday, July 24:

- Dawood's raster-scan structure and configurable geometry were understood;
- the two workspaces and their responsibilities were clarified;
- missing MoveIt, RealSense-description, and UR-driver dependencies were identified;
- the UR5e bringup and controller requirements were established;
- a recorded six-joint scan trajectory was available as JSON;
- the replay node could load the JSON and connect to the controller and capture pipeline;
- the JSON was verified to contain continuous, reasonably timed points;
- the unsafe step-2 rejection was isolated to the controller replay path rather than the recorded raster geometry;
- a 0.25-second lead-in was added to each replayed segment;
- motion-only runs were separated from capture-enabled runs;
- the reconstruction request/result interface connected successfully;
- one integrated capture was eventually accepted and written to the global PLY;
- the capture completed too late for the replay node's 15-second timeout;
- delayed synchronized RGB-D delivery became the next integration blocker;
- scan finalization with pending captures was identified as a code-level lifecycle issue;
- the full multi-step robot scan was not yet considered validated.

---

## Next Steps

1. rebuild `arm_scan_motion` with the 0.25-second trajectory lead-in;
2. verify `joint_trajectory_controller` is active before every replay;
3. rerun step 1 with `capture_enabled:=false`;
4. cautiously validate step 2 only after the time and controller checks pass;
5. measure the publication rates of RGB, aligned depth, and camera-info topics;
6. compare their header timestamps and identify the synchronization delay;
7. inspect the reconstructor's five-frame burst and message-filter behavior;
8. temporarily raise the capture-result timeout only if needed for controlled testing;
9. prevent scan completion from finalizing while captures remain pending;
10. validate the camera-to-tool transform and physical mount orientation;
11. confirm the raster axes and look angle match the installed camera;
12. increase `max_steps` incrementally rather than immediately running the full scan;
13. record a new four-row, 15-degree trajectory after motion safety is confirmed;
14. run the complete move–settle–capture sequence;
15. inspect the fused PLY for coverage, registration quality, and tree detail.

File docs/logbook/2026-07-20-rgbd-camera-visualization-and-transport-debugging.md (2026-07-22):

# 2026-07-20 — RGB-D Transport Debugging and Dawood Reconstruction Pipeline Review

## Objective

Continue directly from Friday’s successful ROS 2 Humble networking setup and remote topic discovery, validate that the Warthog and Jetson RGB-D streams could be viewed from the laptop, and begin understanding Dawood’s UR5e tree-scanning and point-cloud reconstruction code well enough to adapt it for a new use case.

The longer-term objective is to reuse the relevant portions of Dawood’s algorithm to:

1. scan spring and fall trees with the UR5e-mounted RGB-D camera;
2. reconstruct full tree geometry without relying on dormant-tree skeletonization;
3. save the reconstruction as a persistent 3D asset;
4. convert it into a mesh or another Gazebo-compatible model format; and
5. import the model into the Warthog simulation so it can operate in environments beyond the existing dormant-tree scene.

The work therefore had two connected tracks:

* **Track A:** validate RGB-D visualization and transport over the current ROS 2 network;
* **Track B:** reverse-engineer Dawood’s ROS 1 motion, reconstruction, registration, semantic segmentation, and skeletonization pipeline.

---

## Executive Summary

### RGB-D transport

The laptop successfully displayed images from both the Warthog camera and the Jetson-connected RGB-D camera in RViz2. This confirmed that ROS 2 discovery, cross-machine communication, image message transport, and basic decoding were working.

The remaining visualization problem was performance rather than discovery. RViz received only about:

```text
4 messages at approximately 0.2 Hz
```

or roughly one frame every five seconds.

The likely bottlenecks were narrowed to:

* raw image bandwidth over Wi-Fi;
* Reliable QoS retransmitting old packets;
* multiple simultaneous image, depth, and point-cloud streams;
* a low publisher rate on the Jetson;
* missing compressed image transport support in the local ROS 2 Humble environment;
* or a WSL (earlier)/network transport limitation.

### Dawood reconstruction code

Dawood’s repository contains two conceptually separate pipelines:

```text
Pipeline A — Relevant to this project

UR5e motion
→ synchronized RGB-D capture
→ camera-to-base TF
→ RGB-D point-cloud generation
→ coarse-to-fine point-to-plane ICP
→ filtering and global fusion
→ reconstructed point cloud
```

```text
Pipeline B — Mostly not needed initially

semantic trunk/branch labels
→ DBSCAN component extraction
→ spline skeleton fitting
→ parent/child branch relationships
→ branch length and diameter estimation
```

The reusable core is the acquisition, TF, RGB-D reconstruction, ICP, filtering, and rosbag workflow. The semantic reconstruction and skeletonization layers are specialized for dormant woody trees and would likely remove most leaves from a spring or fall tree.

The current code does **not** save a final surface model, generate an STL, or create a Gazebo model. Those steps still need to be added.

---

# Track A — RGB-D Camera Visualization and Transport Debugging

## Switched to a Dedicated Linux Laptop

Today, I received a Linux laptop running Pop!_OS 22.04 for the project. This replaced the WSL environment on my personal laptop, which had been slow and only had ROS 2 Jazzy installed rather than ROS 2 Humble.

The ROS distribution mismatch and WSL performance limitations likely contributed to some of the networking, visualization, and package-compatibility errors encountered on Friday. Using a native Ubuntu 22.04-based system with ROS 2 Humble provides a more appropriate and consistent environment for the Warthog and Jetson setup.

## Displayed Remote Camera Streams in RViz2

Launched RViz2 from the Ubuntu 22.04 / ROS 2 Humble environment and added Image displays for:

```text
/sensors/camera_0/color/image
```

and:

```text
/sensors/camera_jetson/color/image_raw
```

Both topics produced visible images.

This confirmed that:

* the laptop could discover the remote camera publishers;
* ROS image messages could cross from the Warthog and Jetson network into my environment;
* the camera topics used compatible ROS message types;
* RViz could subscribe to and decode at least some frames;
* the issue was no longer a complete ROS networking or discovery failure.

---

## Identified a Very Low Received Image Rate

Although images appeared, they did not update reliably in real time.

RViz reported approximately:

```text
4 messages received at 0.2 Hz
```

This corresponds to approximately one frame every five seconds.

The displayed image could therefore remain several seconds behind the physical camera view. Standing in front of the camera did not consistently appear immediately in RViz.

RViz reporting:

```text
Status: OK
```

only established that valid messages were being received and decoded. It did not mean the stream was operating at a usable live rate.

---

## Inspected RViz Image QoS Settings

The Image displays were initially configured with:

```text
Reliability Policy: Reliable
History Policy: Keep Last
Depth: 5
Durability Policy: Volatile
```

For high-bandwidth sensor streams over Wi-Fi, Reliable delivery may repeatedly retransmit missing data and deliver stale frames.

The preferred live-visualization configuration is:

```text
Reliability Policy: Best Effort
History Policy: Keep Last
Depth: 1
Durability Policy: Volatile
```

This prioritizes the newest available frame and limits stale-frame buildup.

---

## Attempted to Use Compressed Image Transport

Attempted to switch RViz from raw image transport to compressed image transport.

RViz returned:

```text
Error subscribing: Unable to load plugin for transport
'image_transport/compressed_sub'
```

The plugin loader reported that only:

```text
image_transport/raw_sub
```

was available.

This established that the local ROS 2 Humble installation did not have the compressed image subscriber plugin installed.

Expected packages include:

```bash
ros-humble-image-transport-plugins
```

and possibly:

```bash
ros-humble-compressed-image-transport
```

---

## RGB-D Transport Findings

ROS 2 networking is functioning. The remaining slowdown is likely related to transport, QoS, publishing rate, or bandwidth.

Potential causes include:

* raw RGB traffic overwhelming Wi-Fi;
* Reliable QoS retransmissions;
* simultaneous RGB, depth, aligned depth, and point-cloud traffic;
* a low publishing rate at the source;
* receiving fewer frames than the Jetson publishes locally;
* or competing traffic from the Warthog and Jetson.

Compressed topics may exist remotely, but RViz cannot use them locally until the appropriate transport plugin is installed.

---

# Track B — Dawood Code Review

## Intended Adaptation

Dawood’s code was reviewed to determine which components can be reused to scan leafy seasonal trees.

The goal is **not** to reproduce his full dormant-tree analysis. The immediate goal is to reuse:

* UR5e camera motion;
* synchronized RGB-D acquisition;
* camera pose retrieval;
* per-frame point-cloud generation;
* frame-to-map registration;
* point-cloud fusion;
* and offline replay.

The desired output is a dense tree reconstruction suitable for later mesh generation and Gazebo import.

---

## Repository-Level Pipeline

The reviewed files form the following pipeline:

```text
motion_planner.py
    UR5e movement commands
            ↓
camera moves around the tree
            ↓
RGB image + registered depth + CameraInfo + TF
            ↓
pointcloud_processing.py
    segmentation
    → RGB-D point cloud
    → base-frame transform
    → multiscale ICP
    → filtering
    → accumulated point cloud
            ↓
/output_point_cloud
            ↓
skeletonization.py
    semantic class separation
    → DBSCAN
    → fitted tree components
            ↓
tree_component.py
    spline centerlines
    → parent/child relationships
    → lengths and diameters
            ↓
/final_pointcloud and /skeleton_visualizer
```

The repository supports both live and offline workflows.

---

# `motion_planner.py`

## Purpose

Controls the UR5e using:

* the ROS controller manager;
* a `FollowJointTrajectory` action server;
* cuRobo motion planning;
* a UR5e robot configuration;
* a collision-world configuration;
* and hardcoded relative tool motions.

The selected controller is:

```text
scaled_pos_joint_traj_controller
```

which is appropriate for a physical UR robot because it respects UR speed scaling.

---

## Main Motion Flow

The motion execution path is:

```text
/joint_states
→ current joint positions
→ cuRobo forward kinematics
→ current end-effector pose
→ relative pose multiplication
→ cuRobo motion plan
→ ROS JointTrajectory
→ UR5e trajectory action server
```

The code uses:

```text
ur5e.yml
collision_table.yml
```

as cuRobo configuration files.

These are still required to fully reproduce the motion setup.

---

## Important Motion-Planning Findings

### The current main block runs pruning, not scanning

The active code calls:

```python
trajectory_controller.pruning_mode()
```

while:

```python
trajectory_controller.scanning_mode()
```

is commented out.

The file must not be run expecting the scanning pattern without changing this.

### Joint ordering is handled unsafely

The callback records both joint names and positions, but the planner later performs:

```python
joint_positions[0], joint_positions[2] = (
    joint_positions[2],
    joint_positions[0],
)
```

This assumes a fixed incoming order. A safer implementation should map positions by joint name.

### CUDA is hardcoded

The code explicitly uses:

```text
cuda:0
```

and therefore expects a CUDA-capable GPU.

### The action client does not explicitly wait for its server

The controller-manager service is awaited, but the trajectory action client should also call:

```python
wait_for_server()
```

before sending the first goal.

### Relative-pose conventions must be verified

The target pose is constructed by multiplying the current end-effector pose by a relative pose. The relative translation is therefore likely expressed in the tool/end-effector frame rather than directly in `base_link`.

This must be confirmed before designing a new scan pattern.

### Quaternion handling needs cleanup

The code uses rotation values such as:

```text
[1, -0.2, 0, 0]
```

which are not normalized unit quaternions.

cuRobo appears to use a quaternion order consistent with:

```text
[w, x, y, z]
```

because `[1, 0, 0, 0]` is used as identity.

ROS static TF uses:

```text
[x, y, z, w]
```

These conventions must not be mixed.

### `go_home()` is not planned through cuRobo

The home motion is a hardcoded joint trajectory:

```text
[-0.06, -1.25, 2.3, -3.76, -1.57, -3.14]
```

executed over two seconds.

It may not receive the same collision checking as the cuRobo-planned motions. It must be validated for the current robot, camera mount, table, cables, and specimen placement before execution.

### The scan path is a hardcoded relative raster

`scanning_mode()` uses a long series of relative motions that approximately form horizontal sweeps separated by vertical moves.

This resembles a raster scan, but it is difficult to:

* verify absolute workspace limits;
* restart midway;
* adapt to another tree size;
* reason about final camera positions;
* or guarantee repeatability after a failed move.

A better adaptation would generate named absolute viewpoints from parameters such as:

```text
scan width
scan height
rows
columns
camera standoff
camera orientation
```

---

# `pointcloud_processing.py`

## Purpose

This file performs most of the reconstruction work.

It:

* synchronizes RGB, depth, and camera-information messages;
* runs semantic segmentation;
* retrieves the camera pose from TF;
* creates Open3D RGB-D point clouds;
* transforms them into `base_link`;
* refines alignment with multiscale ICP;
* filters and fuses accepted frames;
* publishes the accumulated cloud;
* records reconstruction metrics;
* and invokes skeletonization at shutdown.

---

## Subscribed Topics

The ROS 1 reconstruction node expects:

```text
/rgb/image_raw
/depth_to_rgb/hw_registered/image_rect_raw
/rgb/camera_info
```

The depth image is already registered to the RGB image, allowing a color or segmentation pixel to correspond to the same physical ray as its depth value.

---

## Synchronization

The code uses:

```python
ApproximateTimeSynchronizer(..., queue_size=10, slop=0.001)
```

The allowed timestamp difference is only:

```text
1 millisecond
```

This may be unnecessarily strict and could reject valid RGB-D pairs. Actual message timestamp differences should be measured before preserving this setting.

---

## Segmentation

The active model is YOLO:

```python
self.model = YOLO(rospy.get_param("/model_path"))
```

The alternative BiSeNet wrapper is present but commented out.

The YOLO masks are painted into three exact semantic colors:

```text
trunk:            [0, 0, 1] in Open3D
primary branch:   [0, 1, 0]
secondary branch: [1, 0, 0]
```

Unsegmented pixels remain black.

The reconstruction later removes black points, which means it discards any geometry not classified as trunk or branch.

This is likely unsuitable for spring and fall trees because a dormant-tree model may classify leaves as background and delete most canopy geometry.

The first adapted reconstruction should therefore bypass class-specific segmentation.

---

## Hardcoded Image Resolution

The segmentation image is allocated as:

```text
1280 × 720
```

This should instead use the incoming image shape.

---

## TF-Based Camera Placement

At each camera timestamp, the code requests:

```text
base_link ← rgb_camera_link
```

The transform is converted into a 4×4 homogeneous matrix and applied to the new point cloud.

Conceptually:

```text
point in base frame
=
T(base_link ← rgb_camera_link)
× point in camera frame
```

This provides the initial frame placement before ICP.

Accurate robot kinematics, camera extrinsics, and timestamp synchronization are therefore central to reconstruction quality.

---

## Depth Handling

The depth image is decoded as:

```text
16UC1
```

and all values greater than:

```text
1000 mm
```

are set to zero.

The code comment incorrectly says this represents two meters. It is actually one meter.

The cutoff should be a ROS parameter rather than a hardcoded value.

---

## RGB-D Back-Projection

Open3D combines the semantic color image and registered depth image into an RGB-D image, then uses the RGB camera intrinsics:

```text
fx
fy
cx
cy
```

to back-project pixels into 3D.

The resulting cloud is initially in the RGB camera frame, then transformed into `base_link`.

The code should explicitly specify Open3D’s depth scale and truncation instead of relying on defaults.

---

## ICP Registration

Each new frame is registered against the accumulated global cloud.

The process begins with the TF-aligned cloud and identity ICP correction:

```text
new camera frame
→ transform using TF
→ ICP correction against global cloud
```

The registration is recursive and coarse-to-fine:

```text
SN3 → SN2 → SN1 → SN0
```

Every scale must pass its fitness and RMSE acceptance criteria. If any scale fails, the entire frame is rejected.

The method is point-to-plane ICP, which requires estimated normals.

---

## Filtering and Fusion

For accepted frames, the code:

1. applies the ICP correction;
2. voxel-downsamples the frame;
3. performs radius outlier removal;
4. adds it to the accumulated global cloud;
5. applies semantic class-based downsampling;
6. removes black points for publication;
7. publishes `/output_point_cloud`.

The first frame is downsampled to 10 mm, while later frames are downsampled to 8 mm.

Radius outlier removal uses:

```text
minimum neighbors: 8
radius: 14 mm
```

These values may remove small leaf and twig structures and will need evaluation on leafy trees.

---

## Capture Coordination Problem

The motion node has a `capture_alert` publisher, and the reconstruction node subscribes to it.

However:

* most `capture_alert` publications are commented out;
* `capture_data` starts as `True`;
* and the reconstruction node sets it back to `True` after each processed frame.

The nodes therefore do not currently implement a reliable:

```text
move
→ settle
→ capture exactly one synchronized RGB-D frame
→ confirm completion
→ move again
```

workflow.

The robot could be moving while frames are fused, increasing the risk of:

* motion blur;
* depth distortion;
* stale or mismatched TF;
* low ICP fitness;
* or registration drift.

A capture-request/capture-complete handshake should be added.

---

## No Persistent Point-Cloud Export

The node publishes the reconstruction but does not save the fused point cloud.

At minimum, the adapted node should write:

```text
PLY
PCD
```

files.

PLY is a good master output because it can preserve geometry and color.

The existing `save_frame_data()` function is currently commented out and saves only:

* color image;
* camera intrinsics;
* TF placement;
* ICP correction.

It should also save the depth image or preserve the source rosbag.

---

## Offline Shutdown Behavior

The node starts a wall-clock watchdog that shuts down after eight seconds without a message.

This is useful for rosbag playback but unsafe for live experiments because a normal pause between robot views could terminate the node.

At shutdown, it:

* logs frame and ICP metrics;
* writes JSON and CSV files;
* and runs final skeletonization.

Skeletonization should be disabled in the initial leafy-tree adaptation.

---

# Launch Files

## `system_bringup.launch`

Starts the physical system:

```text
UR5e driver
Azure Kinect driver
camera mounting transform
```

The physical UR5e uses a robot-specific calibration file:

```text
ur_calibration/etc/my_robot_calibration.yaml
```

This is preferable to nominal UR5e kinematics.

The Azure Kinect launch supplies the RGB, registered depth, and camera-info topics.

The live camera mount transform is:

```text
tool0 → camera_base
translation: 0.0000, 0.0485, 0.1325 m
quaternion:  0.5, 0.5, 0.5, -0.5
```

Because ROS static TF uses quaternion order:

```text
qx qy qz qw
```

this should not be interpreted using cuRobo’s apparent `wxyz` ordering.

The full expected TF chain is approximately:

```text
base_link
→ robot links
→ tool0
→ camera_base
→ Azure Kinect camera frames
→ rgb_camera_link
```

---

## `reconstruct_online.launch`

Loads:

```text
params.yaml
tree_yolov8n.pt
```

and starts:

```text
pointcloud_processing.py
motion_planner.py
RViz
```

The smaller YOLO model appears intended for online speed.

This launch file does not start the robot or camera drivers, so `system_bringup.launch` must already be running.

The architecture intends the motion and reconstruction nodes to run together, but the exact Python versions reviewed are not yet configured for clean live scanning because the motion main block uses `pruning_mode()` and the capture handshake is incomplete.

---

## `record_bag.launch`

Records:

### Required reconstruction topics

```text
/rgb/image_raw
/rgb/camera_info
/depth_to_rgb/hw_registered/image_rect_raw
/joint_states
/tf
/tf_static
```

### Additional diagnostic topics

```text
controller goals
controller feedback
controller results
robot mode
safety mode
speed scaling
tool data
wrench
I/O states
```

This is valuable because the physical scan can be performed once and reconstruction can be tuned repeatedly offline.

The bag output path is Dawood-specific and must be changed.

The `rosbag record` launch syntax may also contain a redundant `record` argument, and `-o` may create a timestamped prefix rather than the exact requested `.bag` filename. This should be tested before relying on it.

---

## `reconstruct_offline.launch`

Enables simulated ROS time and replays a bag with:

```text
--clock
--delay 5
--rate 1.0
```

It loads:

```text
tree_yolo11m.pt
params.yaml
skeletonization_params.yaml
```

The larger YOLO model appears intended for higher-accuracy offline processing.

The offline launch defaults to nominal UR5e kinematics, while the live launch uses the physical robot calibration. The same physical calibration should ideally be used offline if TF is reconstructed from recorded joint states.

A major unresolved discrepancy exists between the live and offline camera transforms.

Live:

```text
tool0 → camera_base
nonidentity rotation
```

Offline active transform:

```text
tool0 → azure
identity rotation
```

A commented offline line matches the live transform.

This suggests the active offline transform may be a workaround for a particular recorded bag or TF hierarchy. The correct chain must be verified with a live or replayed TF tree before trusting reconstructed dimensions.

---

# ICP Configuration in `params.yaml`

The registration stages are:

| Stage | Resolution / correspondence scale | Maximum iterations | Maximum accepted RMSE | Minimum fitness |
| ----- | ---: | ---: | ---: | ---: |
| SN3 | 50 mm voxel | 50 | 25 mm | 0.55 |
| SN2 | 20 mm voxel | 20 | 12 mm | 0.55 |
| SN1 | 10 mm voxel | 10 | 6 mm | 0.55 |
| SN0 | full cloud, 10 mm correspondence limit | 5 | 6 mm | 0.55 |

The coarse-to-fine sequence is:

```text
50 mm
→ 20 mm
→ 10 mm
→ full resolution
```

At each stage:

* higher fitness is better;
* lower inlier RMSE is better;
* and failure at any stage rejects the frame.

The convergence-change thresholds are:

```text
relative RMSE:    1e-7
relative fitness: 1e-7
```

These determine when ICP stops changing, not whether the frame is accepted.

The YAML also contains downsampling settings that the reviewed Python file does not use. The Python code instead hardcodes several voxel sizes. This indicates stale configuration or an incomplete refactor.

For leafy trees, the uniform minimum fitness of `0.55` may be difficult to maintain because:

* leaves move;
* depth edges are noisy;
* neighboring views see different occluded surfaces;
* and wind violates ICP’s rigid-scene assumption.

These values should be measured first rather than changed blindly.

---

# Alternative Segmentation: `bisenetv1_eca_predict.py`

This is an alternative semantic segmentation wrapper.

It:

* loads a BiSeNetV1 + Efficient Channel Attention model;
* normalizes an RGB image;
* resizes dimensions to multiples of 32;
* predicts a per-pixel class;
* returns either the integer mask or a colored overlay.

The active reconstruction code uses YOLO instead.

BiSeNet performs semantic segmentation directly, while YOLO produces instance masks that are later reduced to class colors.

For this project, neither model should be required for the initial geometry-only scan. A future model might instead classify:

```text
tree or vegetation
versus
background
```

for leafy canopies.

---

# Skeletonization Pipeline

## `skeletonization.py`

This file converts the semantically colored fused cloud into:

```text
trunk
primary branches
secondary branches
```

It uses:

* exact semantic colors;
* voxel downsampling;
* DBSCAN clustering;
* distance-to-parent filtering;
* minimum-length filtering;
* branch-height filtering;
* spline fitting;
* diameter estimation;
* and ROS marker visualization.

The code can operate either as a standalone subscriber to `/output_point_cloud` or be invoked directly at reconstruction shutdown.

The launch files reviewed do not start the standalone skeletonization node, so the shutdown path appears to be the active path.

---

## `skeletonization_params.yaml`

### Trunk

```text
color: [0, 0, 1]
voxel size: 8 mm
minimum height: 0.5 m
DBSCAN radius: 20 mm
minimum samples: 15
slice thickness: 20 mm
spline samples: 400
```

### Primary branches

```text
color: [0, 1, 0]
voxel size: 10 mm
maximum parent distance: 0.1 m
minimum length: 0.05 m
DBSCAN radius: 30 mm
minimum samples: 5
parent-obstacle removal: 15 mm
slice thickness: 10 mm
spline samples: 100
```

### Secondary branches

```text
color: [1, 0, 0]
voxel size: 0.000005 m
maximum parent distance: 0.06 m
minimum length: 0.02 m
DBSCAN radius: 30 mm
minimum samples: 4
parent-obstacle removal: 10 mm
slice thickness: 5 mm
spline samples: 50
```

The secondary voxel size is:

```text
0.000005 m = 0.005 mm
```

which is implausibly small relative to Azure Kinect depth precision and is likely stale or erroneous.

---

# `tree_component.py`

## Purpose

Represents an individual trunk or branch as a structured component containing:

```text
raw point cloud
fitted centerline
parent
children
junction point
length
direction
diameter measurements
representative diameter
```

This creates a hierarchy such as:

```text
trunk
├── primary branch
│   ├── secondary branch
│   └── secondary branch
└── primary branch
```

---

## Centerline Fitting

The main process is:

```text
raw component cloud
→ PCA dominant direction
→ slices perpendicular to that direction
→ centroid per slice
→ optional parent junction insertion
→ B-spline fitting
→ fixed number of fitted points
```

This creates a skeleton centerline for each component.

---

## Length and Diameter Findings

Several implementation details appear experimental or inconsistent:

* fitted length is calculated as endpoint-to-endpoint distance rather than spline arc length;
* comments refer to a 6 cm branch measurement region, but the code uses 15 cm;
* comments refer to a 6 cm trunk region, but the code uses 10 cm;
* comments mention a 30th or 40th percentile, but the implementation uses a weighted average;
* diameter is calculated after discarding the local `y` coordinate rather than using a true local 2D basis perpendicular to the branch;
* trunk selection appears to minimize absolute mean `x`, despite a comment mentioning both X and Y;
* secondary branch assignment depends on primary-branch iteration order;
* empty parent point clouds are not safely handled before KD-tree construction.

These issues are relevant if reproducing Dawood’s horticultural measurements, but they do not invalidate the basic RGB-D reconstruction and ICP approach.

---

# `pc_utils.py`

Provides shared helpers for:

```text
DBSCAN clustering
voxel downsampling
cluster visualization
Open3D → ROS PointCloud2 conversion
```

The Open3D-to-ROS conversion is duplicated in `pointcloud_processing.py` and should be consolidated.

---

# `test.py`

Only publishes an example RViz `LINE_STRIP`.

It does not test:

* motion planning;
* point-cloud reconstruction;
* semantic segmentation;
* skeletonization;
* or Gazebo conversion.

It can be ignored for the current objective.

---

# `tfs.rviz`

The saved RViz configuration confirms the intended outputs:

| Topic | Intended meaning |
| --- | --- |
| `/inference` | segmentation visualization |
| `/original_point_cloud` | intended raw point cloud |
| `/output_point_cloud` | accumulated semantic reconstruction |
| `/final_pointcloud` | fitted skeleton points |
| `/skeleton_visualizer`  | centerlines, diameter markers, and labels |

The fixed frame is:

```text
base_link
```

The current reconstruction node creates `/original_point_cloud` but does not publish to it, indicating an incomplete or outdated code path.

---

# Relevance of Each Pipeline to the Gazebo Goal

## Reuse directly

```text
UR5e motion framework
camera topic synchronization
camera intrinsics
camera-to-base TF
RGB-D back-projection
multiscale ICP
frame acceptance metrics
voxel downsampling
outlier filtering
rosbag recording
offline replay
```

## Remove or bypass initially

```text
YOLO class coloring
BiSeNet branch classes
black-point semantic deletion
class-specific voxel downsampling
skeletonization
DBSCAN branch extraction
diameter measurement
paper figures
paper timing outputs
```

## Potentially reuse later

The fitted skeleton could eventually generate a lightweight procedural model:

```text
centerlines
→ cylinders or tapered tubes
→ simplified trunk and branch collision geometry
→ procedural canopy
```

This would be useful for a lightweight synthetic Gazebo tree but would not be a scan-faithful leafy surface.

---

# Missing Dependencies and Information

The following items are still needed to reproduce the system fully:

```text
ur5e.yml
collision_table.yml
YOLO model weights
physical robot calibration
verified camera-mount calibration
complete live TF tree
complete offline TF tree
package and environment versions
possibly BiSeNet lib/ files
representative rosbag
```

The highest-priority unresolved issue is the live/offline camera-frame discrepancy:

```text
live:    tool0 → camera_base with nonidentity rotation
offline: tool0 → azure with identity rotation
```

The correct `base_link → rgb_camera_link` chain must be verified before trusting metric reconstruction.

---

# Recommended Adaptation Plan

## Phase 1 — Single Stationary Frame

1. Receive RGB, registered depth, and camera intrinsics.
2. Generate an unsegmented RGB point cloud.
3. Transform it into `base_link`.
4. Save it as PLY.
5. Inspect it in Open3D or CloudCompare.

Do not use:

```text
segmentation
ICP
skeletonization
robot motion
```

during this phase.

---

## Phase 2 — Two-View Fusion

1. Move the camera once.
2. Stop and allow the robot to settle.
3. Capture a second frame.
4. Compare:

   * TF-only alignment;
   * TF plus ICP alignment.
5. Save both results.
6. Inspect fitness, RMSE, and visible double surfaces.

This validates:

* camera extrinsics;
* timing;
* depth registration;
* neighboring-view overlap;
* and ICP settings.

---

## Phase 3 — Small Controlled Scan

Use approximately five deliberate viewpoints rather than the complete hardcoded scan.

At each viewpoint:

```text
move
→ settle
→ request one capture
→ receive capture-complete acknowledgment
→ move to next viewpoint
```

Save:

```text
RGB
depth
CameraInfo
TF
ICP correction
individual frame cloud
accumulated cloud
per-frame registration metrics
```

---

## Phase 4 — Leafy Tree Reconstruction

Begin without semantic branch segmentation.

Then test:

```text
workspace crop
ground or table removal
tree-versus-background segmentation
statistical filtering
radius filtering
multiple scan sides
```

A single frontal raster may not reconstruct the back of a dense canopy. Complete tree geometry will require viewpoints from multiple sides or a rotated specimen.

Outdoor scanning also introduces wind-driven nonrigid motion, which can reduce ICP fitness.

---

## Phase 5 — Mesh and Gazebo Preparation

Once a reliable point cloud is produced:

1. remove background, table, and ground;
2. estimate and orient normals;
3. test Poisson or ball-pivoting reconstruction;
4. remove unsupported or low-density surfaces;
5. repair or intentionally preserve holes;
6. simplify the visual mesh;
7. create a much simpler collision representation;
8. preserve metric scale;
9. export visual and collision assets;
10. create the Gazebo model metadata.

Likely output roles:

```text
PLY: master colored point cloud
OBJ / DAE / glTF: visual mesh
STL or primitive decomposition: simplified collision geometry
```

The collision geometry should generally be much simpler than the visual mesh for Warthog simulation performance.

---

# Current Blockers

## RGB-D transport

1. Compressed image transport is missing locally.
2. Jetson-local and received frame rates have not been compared.
3. Best Effort plus queue depth 1 has not yet been measured.
4. The precise bottleneck among camera driver, Jetson, DDS, and Wi-Fi remains unknown.
5. Multiple high-bandwidth streams may be competing for bandwidth.

## Reconstruction

1. The current motion file runs pruning mode instead of scanning mode.
2. The old scan path has not been validated for the current physical setup.
3. Capture coordination is incomplete.
4. The camera TF chain has not been verified.
5. Live and offline camera transforms differ.
6. The physical UR5e calibration and cuRobo configuration files are still needed.
7. The code does not save the final fused point cloud by default.
8. The code does not generate a mesh or Gazebo model.
9. Dormant-tree segmentation will likely remove leafy canopy geometry.
10. The live ROS 2 system and Dawood’s ROS 1 code still require integration or porting.

---

# Decisions

* Continue using Ubuntu 22.04 / ROS 2 Humble for Warthog and Jetson visualization.
* Treat ROS discovery as resolved.
* Prefer Best Effort QoS and queue depth 1 for live image viewing.
* Prefer compressed image transport over Wi-Fi.
* Avoid visualizing multiple high-bandwidth streams simultaneously.
* Prefer Ethernet or direct Jetson recording for full-resolution RGB-D capture.
* Preserve raw RGB-D and TF data in rosbags rather than relying only on a live fused cloud.
* Separate Dawood’s acquisition/reconstruction core from his semantic skeletonization layer.
* Begin the new reconstruction with original RGB or geometry-only clouds.
* Do not run the full hardcoded scanning path on the UR5e until its workspace and collision assumptions are validated.
* Use a stop–settle–capture handshake for physical scanning.
* Save PLY/PCD outputs before attempting mesh generation.
* Treat STL as a possible collision format rather than necessarily the best visual asset format.

---

# Next Actions

## RGB-D transport

1. Install image transport plugins:

```bash
sudo apt update
sudo apt install -y ros-humble-image-transport-plugins
```

2. Verify available transports:

```bash
ros2 run image_transport list_transports
```

3. Restart RViz and use:

```text
Reliability: Best Effort
History: Keep Last
Depth: 1
Durability: Volatile
```

4. Test one camera topic at a time.

5. Measure received frequency:

```bash
ros2 topic hz /sensors/camera_0/color/image
```

```bash
ros2 topic hz /sensors/camera_jetson/color/image_raw
```

6. Inspect publisher QoS:

```bash
ros2 topic info -v /sensors/camera_jetson/color/image_raw
```

7. Measure bandwidth:

```bash
ros2 topic bw /sensors/camera_jetson/color/image_raw
```

8. Compare the same frequency locally on the Jetson.

9. Validate aligned depth and camera-info topics:

```text
/sensors/camera_jetson/aligned_depth_to_color/image_raw
/sensors/camera_jetson/color/camera_info
/sensors/camera_jetson/aligned_depth_to_color/camera_info
```

10. Record a short RGB-D rosbag.

---

## Dawood pipeline adaptation

1. Obtain:

   * `ur5e.yml`;
   * `collision_table.yml`;
   * the physical UR5e calibration;
   * YOLO weights if needed;
   * and a representative rosbag.

2. Inspect the live and offline TF trees.

3. Confirm the exact transform from:

```text
tool0 → rgb_camera_link
```

4. Confirm cuRobo quaternion ordering and relative-pose semantics.

5. Replace manual joint-index swapping with name-based ordering.

6. Add action-server waiting and robust execution failure handling.

7. Create a reduced, parameterized scan routine.

8. Implement:

```text
move
→ settle
→ capture request
→ capture complete
```

9. Build a geometry-only reconstruction mode.

10. Parameterize:

    * topics;
    * camera/base frames;
    * depth cutoff;
    * image resolution;
    * voxel sizes;
    * outlier settings;
    * ICP thresholds;
    * live/offline timeout;
    * output directory.

11. Save:

    * RGB;
    * depth;
    * intrinsics;
    * TF;
    * ICP corrections;
    * individual frame clouds;
    * final fused PLY/PCD;
    * accepted/rejected-frame metrics.

12. Validate one stationary frame, then two frames, then a five-view scan before attempting the original scan path.

13. Only after reconstruction quality is verified, begin mesh reconstruction and Gazebo integration.

---

# End-of-Day Status

The laptop successfully displayed remote Warthog and Jetson RGB images in RViz2, proving end-to-end ROS 2 discovery and image decoding. The stream was still far below real-time performance at approximately `0.2 Hz`, and compressed image transport was unavailable locally.

Dawood’s available repository files were reviewed at the architectural, launch, configuration, and function level. The central reusable method was identified as:

```text
registered RGB-D
→ camera intrinsics
→ camera-to-base TF
→ Open3D point cloud
→ coarse-to-fine point-to-plane ICP
→ filtering
→ global fusion
```

The semantic segmentation and skeletonization layers were identified as research-specific dormant-tree processing that should be disabled for the initial spring/fall reconstruction.

The immediate engineering priority is not yet STL generation. It is to establish a reliable, synchronized, geometry-only RGB-D scan that can be saved as a metric PLY/PCD and reproduced offline from a rosbag. Once that core is verified, the resulting cloud can be cleaned, meshed, simplified, and packaged for Gazebo.
:::

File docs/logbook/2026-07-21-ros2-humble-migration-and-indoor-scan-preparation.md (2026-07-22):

# 2026-07-21 — ROS 2 Humble Migration and Indoor Scan Preparation

## Day Objective

The primary goal for the day became adapting Dawood's ROS 1 tree-reconstruction and UR5e motion pipeline to the software stack currently available on the Warthog:

```text
ROS 2 Humble
+ Gazebo Fortress
+ UR5e end-effector Jetson/RealSense camera
+ cuRobo motion planning
```

The immediate practical milestone remained deliberately limited:

1. Receive one synchronized RGB-D frame from the UR5e-mounted camera.
2. obtain the camera pose through TF.
3. create a colored Open3D point cloud.
4. transform it into a fixed robot frame.
5. save and inspect a PLY file.
6. only after that works, perform a small supervised move–settle–capture scan indoors.

The code was **not** considered ready for an unsupervised grove scan by the end of the day.

---

## Repository Review and Pipeline Separation

Finished mapping the remaining files in Dawood’s repository:

- `bisenetv1_eca_predict.py`
- `skeletonization.py`
- `tree_component.py`
- `pc_utils.py`
- `test.py`
- `skeletonization_params.yaml`
- `tfs.rviz`

The repository contains two largely separable pipelines.

### RGB-D reconstruction pipeline

```text
UR5e motion
→ synchronized RGB-D capture
→ TF-based placement
→ multiscale ICP
→ fused point cloud
→ PLY output
```

### Semantic and structural-analysis pipeline

```text
trunk/branch segmentation
→ DBSCAN clustering
→ spline skeletonization
→ branch length and diameter estimation
```

The first pipeline is directly relevant to scanning a model tree and producing geometry that can later be inspected or adapted for Gazebo. The semantic and skeletonization pipeline was designed primarily for dormant-tree structural analysis and is not required for the first leafy-tree reconstruction test.

For the initial adaptation, the complete RGB-D geometry should be retained, including foliage, rather than filtering the cloud down to only semantically classified woody components.

---

## Initial Geometry-First Adaptation Scope

### Preserved concepts

- synchronized RGB, aligned depth, and camera intrinsics
- TF-based placement into a common frame
- Open3D RGB-D point-cloud generation
- coarse-to-fine point-to-plane ICP
- voxel downsampling
- radius-outlier removal
- ROS point-cloud publishing
- PLY output
- per-frame RGB, depth, transform, and registration metadata

### Removed or bypassed for the first test

- YOLO/BiSeNet trunk and branch classification
- semantic-color background removal
- class-specific point-cloud downsampling
- skeletonization
- branch diameter and length estimation
- paper-specific visualization and reporting code

This reduced the immediate problem to validating camera data, TF, registration, fusion, and output before reintroducing any semantic processing.

---

## ROS 1 Architecture Identified as a Fundamental Blocker

Although the first edits focused on adapting the reconstruction logic, a larger issue became clear: the repository’s two main Python scripts and package configuration were built around ROS 1, while the Warthog system uses ROS 2 Humble.

The original code depended on:

- `rospy`
- `actionlib.SimpleActionClient`
- ROS 1 controller-manager service calls
- ROS 1 `tf.TransformListener`
- ROS 1 duration and timestamp APIs
- `ros_numpy`
- catkin
- ROS 1 parameter-server layout
- old Universal Robots controller names
- hardcoded ROS 1 camera topics

Therefore, incremental fixes alone would not make the pipeline runnable. The motion planner, point-cloud node, utility layer, package configuration, parameters, and launch process all required a ROS 2 migration.

---

## Available ROS 2 Interfaces

Reviewed the ROS 2 topic list on the Warthog. The camera attached to the UR5e is the `camera_jetson` device.

The three primary reconstruction inputs are:

```text
/sensors/camera_jetson/color/image_raw
/sensors/camera_jetson/aligned_depth_to_color/image_raw
/sensors/camera_jetson/aligned_depth_to_color/camera_info
```

Relevant supporting interfaces include:

```text
/tf
/tf_static
/platform/joint_states
```

The topic list alone did **not** establish:

- whether a UR5e `FollowJointTrajectory` action server is active
- which trajectory-controller namespace is correct
- whether `/platform/joint_states` actually contains all six UR5e joints
- whether a complete TF chain exists from the selected fixed frame to the camera optical frame
- whether Gazebo is publishing or bridging `/clock`

These remained mandatory preflight checks.

---

## Full ROS 1 → ROS 2 Humble Migration

Created a first-pass ROS 2 package for the reconstruction and motion-planning pipeline.

### Package and build-system conversion

Replaced the ROS 1 catkin package with a ROS 2 package using:

- `ament_cmake`
- `ament_cmake_python`
- ROS 2 `package.xml` format 3
- installed Python executables
- declared ROS 2 runtime dependencies
- a ROS 2 launch file
- node-specific ROS 2 YAML parameters

The package now includes:

```text
scripts/motion_planner.py
scripts/pointcloud_processing.py
reconstruct/pc_utils.py
config/params.yaml
launch/scan_tree.launch.py
CMakeLists.txt
package.xml
README.md
```

The Python files were syntax-checked successfully. This only verifies parsing and basic packaging; it does not prove compatibility with the live controller, TF tree, cuRobo installation, camera driver, or Gazebo environment.

---

## ROS 2 Motion Planner

Rewrote the main motion script around `rclpy` and the ROS 2 `FollowJointTrajectory` action.

### Major changes

- Replaced `rospy` with an `rclpy.node.Node`.
- Replaced ROS 1 `actionlib` with `rclpy.action.ActionClient`.
- Made the trajectory action namespace configurable.
- Removed automatic assumptions about which controllers should be stopped or started.
- Added explicit checks for:
  - receipt of a valid UR5e joint state
  - availability of the trajectory action server
  - connection to the reconstruction node
- Added a default motion safety interlock:

```yaml
execute_motion: false
```

- Added a CUDA availability check before initializing cuRobo.
- Preserved cuRobo’s joint ordering and mapped controller or prefixed joint names safely.
- Converted cuRobo tensors to CPU Python lists before constructing ROS trajectory messages.
- Treated cuRobo quaternions using its documented `w, x, y, z` convention.
- Replaced the long sequence of accumulated relative motions with a generated absolute snake-pattern raster around the initial end-effector pose.
- Kept the initial end-effector orientation throughout the raster.
- Replaced the unsafe hardcoded home pose with an optional return to the actual scan-start pose.
- Added configurable scan dimensions, row and column counts, scan-plane axes, time scaling, settling time, and execution timeouts.

### Capture synchronization

Implemented a move–settle–capture handshake:

```text
plan trajectory
→ execute trajectory
→ wait for controller result
→ allow the arm/camera to settle
→ publish one capture request
→ wait for reconstruction acknowledgement
→ move to the next pose
```

The motion planner publishes:

```text
/capture_alert
```

The reconstruction node acknowledges each completed capture on:

```text
/capture_done
```

The planner does not proceed to the next raster pose until that acknowledgement arrives. This prevents the previous behavior in which the camera could process frames continuously while the arm was moving.

---

## ROS 2 Point-Cloud Reconstruction Node

Rewrote the reconstruction script around the UR5e Jetson camera topics and ROS 2 APIs.

### Synchronization and camera handling

- Replaced ROS 1 subscribers with ROS 2 `message_filters.Subscriber` objects.
- Used an `ApproximateTimeSynchronizer` for:
  - color image
  - aligned depth image
  - aligned-depth camera intrinsics
- Used sensor-data QoS for camera streams.
- Increased the synchronization tolerance from the overly restrictive original setting to a configurable ROS 2 value.
- Read the camera frame from the incoming message header instead of hardcoding `rgb_camera_link`.
- Added support for common color encodings such as:
  - `rgb8`
  - `bgr8`
  - `rgba8`
  - `bgra8`
  - grayscale
- Added automatic depth-unit handling:
  - `16UC1` interpreted as millimeters with scale `1000.0`
  - `32FC1` interpreted as meters with scale `1.0`
- Added configurable minimum and maximum depth thresholds.
- Corrected the BGR/RGB mismatch before passing color data to Open3D.

### TF2 conversion

- Replaced ROS 1 `tf` with `tf2_ros.Buffer` and `TransformListener`.
- Performed the transform lookup at the sensor timestamp.
- Constructed the homogeneous transform directly from the ROS 2 translation and quaternion.
- Made the fixed reconstruction frame configurable, initially:

```yaml
target_frame: base_link
```

For every frame, the initial point placement is:

```text
point in camera optical frame
→ TF transform at capture time
→ point in target frame
```

### Point-cloud generation and registration

- Constructed a colored Open3D point cloud from aligned RGB-D data.
- Applied the TF transform before ICP.
- Retained coarse-to-fine point-to-plane ICP as a bounded correction rather than using it to compensate for a missing camera calibration.
- Registered against a spatially cropped portion of the global map when enough local points are available.
- Retained configurable multiscale registration thresholds for:
  - voxel size
  - maximum correspondence distance
  - iteration count
  - relative RMSE and fitness convergence
  - acceptance RMSE
  - acceptance fitness
- Added sanity limits for the maximum translation and rotation that ICP is permitted to apply.
- Rejected frames whose registration quality or correction magnitude was implausible.
- Applied configurable local voxel downsampling and radius-outlier removal.
- Downsampled the accumulated global map after accepted frames.

### Capture state and output

- Removed continuous automatic processing.
- Each capture request now queues exactly one synchronized RGB-D capture.
- Kept a capture pending if TF is temporarily unavailable rather than silently consuming it.
- Published the TF-positioned latest frame and the fused global cloud separately:

```text
/tree_scan/latest_tf_cloud
/tree_scan/global_cloud
```

- Wrote the accumulated PLY after every processed capture.
- Saved per-frame RGB, depth, intrinsics, TF, ICP correction, acceptance state, fitness, and RMSE.
- Added a final JSON summary with accepted-frame counts, average ICP metrics, processing time, point count, and PLY path.

The default output location is:

```text
~/tree_scans/indoor_model_tree/global_point_cloud.ply
```

---

## ROS 2 PointCloud2 Utility

Replaced the original ROS 1 `ros_numpy` conversion utility.

The new helper:

- directly constructs a ROS 2 `sensor_msgs/msg/PointCloud2`
- writes `x`, `y`, and `z` as `float32`
- packs RGB into the conventional PCL-compatible field
- preserves the supplied frame ID and sensor timestamp
- removes dependencies on `rospy.Time` and `ros_numpy`

This resolves another ROS 1-only dependency that would otherwise prevent the reconstructed cloud from being published under ROS 2.

---

## Runtime Bugs and Design Problems Addressed

The migration also corrected or replaced several problems identified in the intermediate ROS 1 adaptation:

- The original camera topics did not match the Warthog’s Jetson camera topics.
- The trajectory action interface was ROS 1-specific.
- The original code depended on ROS 1 controller-manager service definitions and old controller names.
- The motion sequence accumulated relative movements and could drift away from the intended scan grid.
- The home pose was hardcoded and unverified for the current physical mounting arrangement.
- Joint-state positions could be interpreted in the wrong order.
- cuRobo trajectory tensors needed explicit CPU/list conversion.
- Quaternion ordering and normalization required explicit handling.
- The reconstruction node automatically re-enabled capture and processed frames continuously.
- First-frame registration variables could be referenced before assignment.
- `save_frame_data()` was called with arguments its signature did not accept.
- A rejected ICP frame could cause metadata-saving failures.
- The original code assumed BGRA color and 16-bit depth regardless of the incoming encoding.
- Open3D received BGR values while treating them as RGB.
- The original TF frames were hardcoded.
- The image counter and file-writing behavior risked overwriting or invalid output.
- The original output directory was hardcoded under `/datasets`.
- The old idle-shutdown thread was suited to rosbag playback but unsafe for a live camera.
- The global ICP target could grow without bound and encourage incorrect correspondences.
- The ROS 1 package did not install the Python scripts or declare the required runtime dependencies.

---

## Indoor Test Procedure Prepared

### Preflight inspection

Before moving the arm, verify the actual ROS 2 interfaces:

```bash
ros2 topic echo /platform/joint_states --once
ros2 action list -t | grep follow_joint_trajectory
ros2 control list_controllers
ros2 topic echo /sensors/camera_jetson/aligned_depth_to_color/camera_info --once
ros2 topic hz /sensors/camera_jetson/color/image_raw
ros2 topic hz /sensors/camera_jetson/aligned_depth_to_color/image_raw
```

Use the camera-info message’s `header.frame_id` to test the TF chain:

```bash
ros2 run tf2_ros tf2_echo base_link <camera_optical_frame>
```

### Reconstruction-only test

Launch the reconstruction node without arm motion:

```bash
ros2 launch reconstruct scan_tree.launch.py \
  execute_motion:=false \
  use_sim_time:=true
```

Trigger one capture manually:

```bash
ros2 topic pub --once \
  /capture_alert \
  std_msgs/msg/Bool \
  "{data: true}"
```

Then inspect:

```text
~/tree_scans/indoor_model_tree/global_point_cloud.ply
```

In RViz:

- set the fixed frame to `base_link`
- add `/tree_scan/latest_tf_cloud`
- add `/tree_scan/global_cloud`

The latest-frame topic helps distinguish a TF or calibration problem from an ICP/fusion problem.

### Initial motion test

Only after a stationary PLY capture works:

1. place the UR5e at a safe manually verified start pose facing the indoor model tree
2. reduce the raster to a very small area
3. confirm that the configured scan axes move across the camera image plane rather than toward the tree
4. run with supervision and low speed
5. verify every capture before increasing scan dimensions

---

## Remaining External Blockers

The code cannot determine these from the topic list alone.

### Trajectory controller

Need to identify the active ROS 2 action name. Likely candidates include:

```text
/joint_trajectory_controller/follow_joint_trajectory
```

for Gazebo/`gz_ros2_control`, or:

```text
/scaled_joint_trajectory_controller/follow_joint_trajectory
```

for the physical Universal Robots ROS 2 driver.

The controller must already be loaded and active.

### Joint states

Need to confirm whether `/platform/joint_states` includes all six UR5e joints or only Warthog platform joints. If not, the correct arm joint-state topic must be supplied.

### Simulation time

The provided topic list did not show `/clock`. A Gazebo Fortress run using:

```yaml
use_sim_time: true
```

requires a working ROS clock bridge. Camera and TF timestamps must use the same time source.

### TF and hand–eye calibration

Need a complete and accurate chain from the fixed robot frame through the UR5e and tool mount to the camera optical frame. ICP should only correct small residual alignment errors; it cannot replace a correct camera extrinsic calibration.

### cuRobo collision models

The default `collision_table.yml` is only a generic example environment. Before physical motion, the collision model should include:

- the actual Warthog-mounted UR5e configuration
- the camera housing and mount
- the floor at the correct height
- nearby walls, tables, and equipment
- a conservative exclusion volume around the model tree

### Physical scan logistics

Still need confirmation from Divyanth or Dawood regarding:

- the correct controller and startup sequence
- current robot and camera calibration files
- whether the original scan path was ever used on this exact mounting configuration
- supervision requirements
- indoor success criteria
- grove transportation, power, weather, permissions, and safety constraints

---

## Version-Control Summary

A suitable commit scope for the day’s work was:

```text
refactor: migrate tree scanning pipeline to ROS2 Humble/Gazebo Fortress
```

The commit encompasses the ROS 2 motion-planning and reconstruction nodes, Jetson camera integration, TF2 conversion, capture synchronization, package migration, PLY output, and runtime/safety fixes.

---

## End-of-Day Status

By the end of Tuesday, July 21:

- The complete repository structure and both major pipelines were understood.
- The reconstruction problem was narrowed to a geometry-first leafy-tree scan.
- The original ROS 1 architecture was identified as incompatible with the Warthog’s ROS 2 Humble stack.
- The two main Python scripts were rewritten as a first-pass ROS 2 implementation.
- The ROS 1 point-cloud conversion utility was replaced.
- The package was converted from catkin to ROS 2 `ament_cmake`/`ament_cmake_python`.
- ROS 2 launch and parameter files were created.
- The UR5e-mounted `camera_jetson` topics were integrated.
- A move–settle–capture acknowledgement sequence was implemented.
- The unsafe relative scan sequence was replaced with a configurable absolute raster.
- The global PLY and per-frame metadata output paths were defined.
- The Python code was syntax-checked.
- The code had **not yet** been validated against the live UR5e controller, the Gazebo Fortress action server, the actual TF tree, or a real RGB-D capture.
- No physical motion or successful complete scan was claimed.

The next immediate milestone is:

```text
verify camera topics and TF
→ capture one stationary PLY
→ inspect cloud orientation and scale
→ verify the UR5e controller and joint-state interfaces
→ run a very small supervised indoor raster
→ tune depth, voxel, outlier, and ICP parameters
→ record a rosbag
→ prepare for a later grove scan
```

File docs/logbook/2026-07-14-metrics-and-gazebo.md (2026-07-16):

7-14-26_day_3_metrics_and_gazebo.md

# Priors
## Read *Benchmark of visual and 3D lidar SLAM systems in simulation environment for vineyards*
- Read the vineyard benchmark and scenario-execution paper. Decide on likely metrics: launch success, map creation success, plan success, completion rate, collisions, time-to-goal, path length, CPU/GPU notes, and qualitative failure categories.

- RTAB achieves superior performance with the lowest RMSE across all scenarios compared to other systems

## Initial Evaluation
How do I evaluate "okay this simulation works well enough"? I need metrics to compare and test whether the environment is simulating correctly. I need to test the robot's navigation (is it bumpy and is this being received; are the rows wide enough, or too wide; is it too long or too short; are trees and plants too hard or too easy, etc), its equipment (if LiDAR, is it working, or RGBD cameras, etc, which SLAM algorithm, etc). 

The paper creates 4 scenarios:
– Scenario 0 (S0): Move in a straight line. That is mainly to evaluate the drift of the generated trajectory. Trajectory length is 25 m.
– Scenario 1 (S1): Send the robot to inspect a row and get back from the same row. Trajectory length is 48.6 m.
– Scenario 2 (S2): Send the robot to inspect a row and get back from the adjacent row. Trajectory length is 54.6 m.
– Scenario 3 (S3): Inspect multiple rows. That is to simulate a real-life inspection scenario with multiple loop closures. Trajectory length is 101.2 m.

## Metrics from Paper
The output trajectory of a SLAM system can be evaluated by finding the absolute distance between the estimated trajectory and the ground truth. The Absolute Trajectory Error (ATE) is defined as the average deviation from the ground truth trajectory.

# Evaluation Goal
The simulator should not be considered complete merely because Gazebo launches and the Warthog can move. It should be evaluated at four levels:

1. Simulation and ROS integration.
2. Sensor and orchard-world correctness.
3. Mapping and localization performance.
4. Autonomous-navigation task performance.

The initial metrics will establish whether the platform is reproducible and useful for pre-field testing. More detailed simulation-to-real validation can be added later.

## Level 1: Simulation and integration health

> "Can the complete system start and communicate correctly?"

| Metric | Measurement |
| --- | --- |
| Launch success | Percentage of launches completing without fatal errors |
| Startup time | Seconds from launch command to ready state |
| Robot spawn success | Did the Warthog spawn at the expected pose? |
| Required topic availability | Percentage of expected ROS topics present |
| TF validity | Missing transforms, disconnected TF trees, timestamp errors  |
| Sensor publication rate | Actual Hz versus configured Hz |
| Simulation real-time factor | Simulated time divided by wall-clock time |
| Repeatability | Does the same configuration behave consistently across runs? |
| Resource usage | Average/peak CPU, GPU, and RAM |
| Crash frequency | Crashes or unrecoverable failures per trial |

## Level 2: Sensor and world correctness

> "Are the world and sensors producing plausible inputs?"

**LiDAR**
- Expected scan or point-cloud topic exists.
- Correct frame ID.
- Expected update rate.
- Maximum and minimum range behave correctly.
- Trees appear as obstacles at plausible distances.
- Ground returns are appropriate for the LiDAR orientation.
- No unexplained missing sectors or self-collisions.
- Point density is consistent with the configured sensor.

**RGB or RGB-D camera**
- Image topic exists.
- Camera info topic exists.
- Depth aligns with RGB, if RGB-D.
- Resolution and frame rate match configuration.
- Objects at known distances have approximately correct depth.
- Camera pose and field of view match the physical mounting.

**IMU and odometry**
- Stationary robot reports approximately zero velocity.
- Straight motion produces plausible linear odometry.
- Turns produce plausible angular motion.
- IMU orientation and acceleration axes are correct.
- No obvious frame-axis inversions.

**Orchard geometry**
- Row width.
- Tree spacing.
- Row length.
- Trunk diameter or obstacle footprint.
- Headland or turning-space width.
- Ground roughness or slope.
- Collision geometry matches visible geometry.
- Robot clearance through rows.

## Level 3: Mapping and localization performance

| Metric | Meaning |
| --- | --- |
| Map creation success | Did the SLAM system produce a usable map? |
| ATE RMSE | Global deviation between estimated and ground-truth trajectories |
| Relative Pose Error | Local drift over short trajectory intervals |
| Final-position drift | Difference between estimated and true final pose |
| Loop-closure success | Whether revisiting an area corrected accumulated drift |
| Map completeness | Percentage of expected orchard structure represented |
| Map consistency | Duplicate rows, warped rows, broken geometry, ghost obstacles |
| Localization loss events | Number of times tracking failed |
| Relocalization time | Time needed to recover after tracking loss |
| Processing rate | Whether SLAM keeps up with sensor data in real time |
| CPU/GPU/RAM | Computational cost of the selected SLAM approach |

ATE tells you how far the estimated trajectory differs from simulation ground truth. Relative Pose Error is also worth adding because a trajectory can have moderate global alignment while accumulating problematic local motion error.

## Level 4: Autonomous-navigation performance

> Can the robot accomplish representative orchard tasks reliably?

| Metric | Suggested definition |
| --- | --- |
| Plan success rate | Valid global plan generated / navigation requests |
| Goal completion rate | Goals reached within tolerance / attempted goals |
| Collision rate | Trials with any collision / total trials |
| Collision count | Number of collision events per trial |
| Time to goal | Seconds from accepted goal to completion |
| Path length | Total distance traveled |
| Path efficiency | Actual path length / shortest feasible or reference path length |
| Planning latency | Time required to produce or re-produce a plan |
| Recovery count | Number of recovery behaviors triggered |
| Intervention count | Manual resets or teleoperation interventions |
| Goal-position error | Final distance and heading error relative to target |
| **Minimum obstacle clearance**| Closest distance to trees or row boundaries |
| **Cross-track error** | Lateral deviation from desired row centerline |
| Oscillation events | Repeated forward/backward or heading corrections |
| Stuck rate | Trials terminated because progress stopped |
| Costmap validity | Missing, stale, inflated incorrectly, or false obstacles |
| Controller command smoothness | Abrupt changes in linear/angular velocity |
| Real-time factor | Whether the experiment ran at usable simulation speed |

## Four Scenarios
### S0 — Straight row traversal

Purpose:

Odometry and localization drift.
Controller stability.
Cross-track error.
Basic sensor and costmap operation.

Metrics:

Completion.
ATE/RPE.
Cross-track RMSE.
Time.
Path length.
Minimum clearance.
Oscillations.

### S1 — Enter row, travel down, return through same row

Purpose:
- Rotation and re-entry.
- Accumulated SLAM drift.
- Reverse-direction perception.
- Potential loop closure.

Metrics:
- Completion.
- ATE/RPE.
- Final pose error.
- Loop-closure behavior.
- Recovery events.
- Collision count.

### S2 — Enter one row, return through adjacent row

Purpose:
- Headland turning.
- Global planning.
- Correct row separation in the map.
- Avoiding false shortcuts through trees.

Metrics:
- Plan success.
- Completion.
- Path efficiency.
- Headland turning clearance.
- Wrong-row entry count.
- Collision count.

### S3 — Multi-row orchard mission

Purpose:
- Longer-duration stability.
- Repeated loop closures.
- Costmap and localization consistency.
- More realistic mission execution.

Metrics:
- Completion rate.
- ATE/RPE.
- Total time.
- Distance.
- Recovery count.
- Localization failures.
- CPU/GPU/RAM.
- Real-time factor.

To Consider Adding:
### S4 — Perturbed or stress-test scenario

Vary one controlled factor:

- narrower rows,
- uneven terrain,
- sensor noise,
- missing trees,
- different lighting, if camera-based,
- reduced LiDAR range,
- increased speed.

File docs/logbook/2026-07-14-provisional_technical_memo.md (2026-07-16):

# MEMO RESCINDED -- REPOSITORY MADE AVAILABLE EARLY JULY 15.

# Provisional Technical Decision Memo — July 14

## Context

The planned meeting with Divyanth did not occur, and the previous intern’s repository and environment specifications remain unavailable. Divyanth has been contacted, but he was not yet able to confirm the software versions, sensor configuration, or repository details.

## Interim Decision

Until the inherited repository is received, I will use the current Clearpath Simulator Jazzy branch and its included orchard world as a reference implementation.

This work is intended to:

* establish familiarity with the Clearpath simulation workflow;
* confirm that a Warthog can be spawned in an orchard environment;
* understand the roles of `robot.yaml`, ROS-Gazebo bridges, launch files, sensors, topics, and transforms;
* identify the information needed to compare the reference stack with Cornell’s physical Warthog;
* prepare reusable topic-audit and reproducibility procedures for the inherited project.

## Environment Decision

The reference simulator will be installed on the lab Linux desktop rather than Windows because the Clearpath instructions and ROS/Gazebo dependency workflow target Linux. Windows support will not be pursued unless later required by the inherited repository.

## Current Assumptions

* The current Clearpath Jazzy/Harmonic simulator may differ from the prior intern’s stack.
* The included orchard world is a reference environment, not necessarily the final Cornell environment.
* The default sensor suite may not correspond to the physical Cornell Warthog.
* No architectural changes will be committed until the inherited repository and robot configuration are reviewed.

## Immediate Outputs

* Linux environment inventory.
* Reproducible installation log.
* Build and launch result.
* Orchard-world screenshot.
* ROS topic and TF inventory.
* List of default sensors.
* CPU/GPU/RAM notes.
* Errors and blockers.
* Questions requiring confirmation from Divyanth or the former intern.

## Pending Decisions

* Inherited repository versus current Clearpath stack.
* ROS and Gazebo versions.
* Mission-critical sensors.
* Physical Warthog correspondence.
* Mapping and navigation stack.
* Final definition of done.
* Research and publication evaluation target.

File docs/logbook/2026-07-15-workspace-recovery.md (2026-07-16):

# July 15 — Inherited Workspace Discovery and Recovery

## Major Development

Access was obtained to the lab Linux desktop previously used by Nidhish. Two substantial ROS 2 workspaces and associated documentation, maps, models, evaluation results, TF diagrams, sensor CAD files, and rosbag recordings were located.

This removes the immediate dependency on waiting for the repository handoff meeting and allows the existing system to be reconstructed before meeting with Nidhish.

## Workspaces Identified

### `cornell_orchard_ws`

Preliminary contents suggest that this workspace contains orchard simulation or mapping work, including:

* source packages;
* a colored orchard point cloud;
* TF diagrams;
* previous build and execution logs.

### `orchard_navigation_rl_ws`

This workspace contains a learned multi-modal navigation architecture for the Warthog, including:

* camera and LiDAR data collection;
* behavior-cloning training;
* learned-policy deployment;
* orchard-world assets;
* command-velocity safety multiplexing;
* odometry diagnostics;
* camera-only, LiDAR-only, and multimodal evaluations;
* model checkpoints and rosbag recordings.

The README specifies ROS 2 Humble and a Warthog/Husky platform.

## Preliminary Architecture

The learned controller uses:

* a Stable Diffusion VAE for visual feature extraction;
* a PointNet encoder for 3D LiDAR features;
* early feature fusion;
* a GRU over 13-frame temporal sequences;
* prediction of linear and angular velocity commands.

## Preliminary Sensor Evidence

The files and TF diagrams provide evidence of:

* an RGB camera;
* 3D LiDAR, likely an Ouster unit;
* an Xsens IMU;
* wheel odometry.

The exact correspondence with the current physical Cornell Warthog remains to be verified.

## Preliminary Evaluation Findings

* LiDAR-only produces the strongest linear-velocity regression performance.
* Multimodal fusion produces the strongest angular-velocity regression performance and turn-classification macro F1.
* Camera-only results are close to a majority-class turn baseline.
* Camera-only and multimodal models fail to detect stop events in the current evaluation.
* All models show weaknesses on minority turn classes.
* Several models produce a narrower velocity range than the ground truth.

These results suggest that closed-loop navigation performance cannot be inferred from the existing offline metrics alone.

## Updated Research Opportunity

A potentially valuable contribution is to connect the existing learned navigation models to the Gazebo orchard environment and build a reproducible closed-loop evaluation framework.

Possible comparisons include:

* camera-only;
* LiDAR-only;
* multimodal fusion;
* conventional Nav2 baseline, if appropriate.

Possible metrics include completion rate, collisions, cross-track error, obstacle clearance, stop success, turning success, path length, runtime, and robustness to controlled environmental variation.

## Immediate Technical Plan

1. Preserve the original directories without modification.
2. Create clean working copies under my account.
3. Record Ubuntu, ROS, Gazebo, CUDA, and dependency versions.
4. inspect Git state and preserve uncommitted files.
5. reconstruct the intended launch sequence from documentation and launch files.
6. rebuild the ROS workspaces from clean source.
7. launch the orchard environment and Warthog.
8. audit topics, nodes, transforms, sensors, and robot footprint.
9. identify where `map → odom → base_link` is generated.
10. document all blockers and missing assumptions.

## Current Questions

* Which workspace and branch represent Nidhish’s final intended system?
* Which files were never committed?
* Which Gazebo version was used with ROS 2 Humble?
* Was the simulator used for training, testing, or only visualization?
* Which physical sensor configuration should be reproduced?
* Are the current evaluation results based on a held-out route, held-out time sequence, or randomly sampled frames?
* How were stop and turn labels defined?
* Is the project’s primary goal imitation learning, Nav2 evaluation, mapping, or a combined system?
* What constitutes the desired publication contribution?

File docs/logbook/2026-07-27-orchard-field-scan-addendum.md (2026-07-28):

# 2026-07-27 — Orchard Field Scan Addendum

## Field Deployment Outcome

The late-day dry window was sufficient to take the Warthog, UR5e, and RealSense system into the orchard. Six reconstruction datasets were produced across five physical trees, providing the first real-tree field validation of the complete motion, capture, retry, registration, saving, and summary pipeline.

All runs used the same core reconstruction settings:

- five-frame depth bursts with at least two valid samples per pixel;
- up to three capture attempts per requested pose;
- 0.3 m minimum depth;
- 3 mm local and global voxel sizes;
- statistical outlier removal;
- TF initialization followed by coarse-to-fine point-to-plane ICP;
- raw capture preservation and final PLY export.

The first five runs used a 2.5 m maximum depth. The final repeat, `outdoor_tree_6`, increased this limit to 3.5 m.

## Reconstruction Summary

| Dataset | Completed pose requests | Accepted requests | Rejected attempts | Mean ICP fitness | Mean ICP RMSE | Final points | Result |
|---|---:|---:|---:|---:|---:|---:|---|
| `outdoor_tree_1` | 32 | 32 | 0 | 0.861 | 3.64 mm | 599,999 | Complete; usable away-from-sun scan |
| `outdoor_tree_2` | 32 | 32 | 0 | 0.915 | 3.39 mm | 664,476 | Complete, but visually unusable because the camera faced the sun |
| `outdoor_tree_3` | 32 | 32 | 0 | 0.836 | 3.78 mm | 1,031,782 | Complete; usable away-from-sun scan |
| `outdoor_tree_4` | 14 | 12 | 6 | 0.802 | 4.24 mm | 660,495 | Partial; two requests exhausted all three attempts |
| `outdoor_tree_5` | 15 | 15 | 0 | 0.810 | 4.13 mm | 737,169 | Partial first attempt on the final tree |
| `outdoor_tree_6` | 32 | 32 | 0 | 0.862 | 3.78 mm | 1,505,222 | Successful 32-view repeat of the final tree |

Across the six datasets, the reconstructor accepted 155 of 157 pose requests. It processed 161 total attempts, of which six were rejected. Four datasets completed all 32 planned views; two preserved useful partial reconstructions.

The `accepted_percent` value in the summary is attempt-based. For example, `outdoor_tree_4` reports 66.7% because 12 of 18 attempts were accepted, although its pose-request success rate was 12 of 14, or 85.7%.

## Direct-Sun Failure

`outdoor_tree_2` was the only run performed while the camera faced the sun. The RealSense depth observations of the tree were largely lost, and the resulting reconstruction was qualitatively unacceptable. All later tests were oriented away from the sun and produced substantially cleaner tree geometry.

This run exposed a critical limitation in the current metrics. Despite being the worst reconstruction visually, `outdoor_tree_2` had:

- the highest mean ICP fitness, 0.915;
- the lowest mean ICP RMSE, 3.39 mm;
- 32/32 accepted capture requests;
- more than 664,000 final points.

ICP fitness and RMSE therefore describe how well the surviving points align; they do not establish that the target tree was captured completely or even that most of the retained points belong to the tree. Final point count has the same limitation because background or otherwise irrelevant geometry can remain dense.

Future acquisition summaries should include target-quality measurements before registration:

- valid-depth percentage within a tree region of interest;
- raw and filtered target-point counts per pose;
- image/depth saturation or invalid-pixel rate;
- per-capture depth coverage and distance distribution;
- the number of captures contributing to each local tree region.

The field evidence supports treating direct sunlight as an acquisition-condition failure that must be detected before ICP acceptance, rather than as a registration problem to solve afterward.

## Partial Runs and Retry Behavior

The two incomplete datasets represent different failure types.

For `outdoor_tree_4`, 12 pose requests were accepted and two requests exhausted all three retries, producing six rejected attempts. The rejected attempts did not contaminate the accumulated cloud, and the accepted portion was still saved. This validated the field retry and partial-result preservation behavior under a more difficult real-tree scene.

For `outdoor_tree_5`, every one of the 15 requests received by the reconstructor was accepted. The summary therefore cannot classify the stop at 15/32 as an ICP or capture rejection; the interruption occurred elsewhere in the motion/run sequence or after the last recorded request. Repeating the same final tree as `outdoor_tree_6` completed all 32 requests successfully, showing that the trajectory and reconstruction pipeline could recover on a clean rerun.

## Interpretation

The orchard deployment established a strong operational baseline:

- the system can execute a complete 32-pose raster and reconstruct real orchard trees in the field;
- the depth-burst, retry, rejection, raw-data, PLY, configuration, and summary mechanisms operated outside the lab;
- away-from-sun orientation was a necessary condition for usable RealSense depth;
- three complete away-from-sun runs produced promising starting reconstructions;
- rejected attempts were isolated rather than fused;
- partial scans remained recoverable for diagnosis;
- a failed partial run on the final tree was followed by a successful 32/32 repeat.

The run summaries are not sufficient to rank geometric reconstruction quality. The apparently excellent ICP statistics of the sun-facing failure reinforce the earlier indoor conclusion that local fitness and RMSE cannot serve as standalone quality metrics. Each dataset must still be evaluated with TF-only, incremental TF+ICP, and TF-anchored pose-graph replay, together with fixed local crops and thin cross-sections through trunks, branches, leaves, and apples.

Point count and reconstruction time also increased substantially across some runs, reaching approximately 1.5 million points and 6.0 seconds mean reconstruction time in `outdoor_tree_6`. These values are influenced by the number of accepted views, scene content, the larger 3.5 m depth range in the final run, and the growing accumulated cloud, so they should be treated as workload indicators rather than direct measures of quality.

## Resulting Experimental Direction

The field data should be preserved as an independent validation set rather than used immediately for method-specific tuning. The next analysis should:

1. inspect each final PLY and label the sun-facing and partial-run failure modes explicitly;
2. calculate per-capture valid-depth and target-point coverage, especially for `outdoor_tree_2`;
3. replay the away-from-sun datasets using TF-only, chronological incremental ICP, and the TF-anchored pose graph;
4. test incremental ICP order sensitivity on at least one complete outdoor scan;
5. compare identical close-up regions around a trunk, branch, visible apple, partially occluded apple, and representative leaves;
6. measure local surface thickness and duplicate shells with fixed thin cross-sections;
7. compare `outdoor_tree_5` and `outdoor_tree_6` only with the configuration and completion differences stated explicitly;
8. reserve TEASER++ or another global pairwise solver for specific overlapping frame pairs that fail robust TF-initialized ICP, rather than using it to address missing sun-corrupted depth.

The primary field conclusion is that the full system is operational and can collect promising real-tree reconstructions, but acquisition completeness must become a first-class metric. Direct sunlight can make a reconstruction unusable while every existing registration statistic still appears successful.

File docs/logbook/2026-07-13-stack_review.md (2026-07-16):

#7-13-26_day_2_stack_review.md

# Stack Notes

## Clearpath Simulator Readme
- ROS2 **Jazzy**, Gazebo **Harmonic**. Need to find out compatible versions/distros with Warthog/current repo, as well as if I need a Linux OS or can get by on Windows.
- What is `robot.yaml`? Is that the Warthog model (or any model, but in my case).
- `Orchard` world parameter will be used for initial clearpath simulator run

### Setup

Prerequisites:
  - Install [ROS 2 Jazzy](https://docs.ros.org/en/jazzy/Installation/Ubuntu-Install-Debians.html)

#### Gazebo Harmonic

See [Gazebo Installation](https://gazebosim.org/docs/latest/ros_installation/) for more information
on installing Gazebo.

```
sudo apt-get install ros-${ROS_DISTRO}-ros-gz
```

#### Workspace

```
mkdir ~/clearpath_ws/src -p
cd ~/clearpath_ws/src
git clone https://github.com/clearpathrobotics/clearpath_simulator.git
cd ~/clearpath_ws
rosdep install -r --from-paths src -i -y
colcon build --symlink-install
```

#### Setup path

```
mkdir ~/clearpath
```

Copy your `robot.yaml` into `~/clearpath`

### Launch

```
ros2 launch clearpath_gz simulation.launch.py
```
Will end up using:
```
ros2 launch clearpath_gz simulation.launch.py world:=orchard
```

## Nav2 Overview
- Uses behavior trees (BT)
- BT allows for customized and intelligent navigation behavior by orchestrating servers
- Provides all major robotic navigation needs: perception, planning, control, localization, visualization, etc.
- Cost maps? Local, global? Need to understand deeper what this means and how it connects. I'm sure it relates to how a robot decides what to do -- optimal path is simply least cost, optimal behavior is least cost, etc.
- From diagram: controller server uses local costmap, planner server uses global costmap -- why the difference?
- Smoother server has "costmap sub., footprint sub.", two bidirectional arrows to BT Nav Server...

## ROS_gz Repo
[x] Read

## Read *Benchmark of visual and 3D lidar SLAM systems in simulation environment for vineyards*
- Read the vineyard benchmark and scenario-execution paper. Decide on likely metrics: launch success, map creation success, plan success, completion rate, collisions, time-to-goal, path length, CPU/GPU notes, and qualitative failure categories.

- RTAB achieves superior performance with the lowest RMSE across all scenarios compared to other systems

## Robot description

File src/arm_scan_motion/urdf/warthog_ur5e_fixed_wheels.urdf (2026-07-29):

<?xml version="1.0" ?>
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
<robot name="w200-0100" xmlns:xacro="http://ros.org/wiki/xacro">
  <xacro:include filename="$(find realsense2_description)/urdf/_d435.urdf.xacro" />
  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
  <link name="world"/>
  <joint name="world_to_base_link" type="fixed">
    <origin xyz="0 0 0" rpy="0 0 0"/>
    <parent link="world"/>
    <child link="base_link"/>
  </joint>

  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
  <link name="base_link"/>
  <joint name="base_link_joint" type="fixed">
    <origin rpy="0 0 0" xyz="0 0 0.025"/>
    <parent link="base_link"/>
    <child link="chassis_link"/>
  </joint>
  <link name="chassis_link">
    <inertial>
      <origin rpy="0 0 0" xyz="0 0 0"/>
      <mass value="100"/>
      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
    </inertial>
    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
  </link>
  <link name="left_diff_unit_link">
    <inertial>
      <origin rpy="0 0 0" xyz="0 -0.05 0.197"/>
      <mass value="50"/>
      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
    </inertial>
    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
  </link>
  <joint name="left_diff_unit_joint" type="fixed">
    <limit effort="100" lower="-0.4" upper="0.4" velocity="1"/>
    <parent link="chassis_link"/>
    <child link="left_diff_unit_link"/>
    <origin rpy="0 0 0" xyz="0.0 0.56821 0.0"/>
    <axis xyz="0 1 0"/>
    <dynamics damping="100" friction="0.5"/>
  </joint>
  <link name="left_diff_unit_headlight_link">
    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
  </link>
  <joint name="left_diff_unit_headlight_joint" type="fixed">
    <parent link="left_diff_unit_link"/>
    <child link="left_diff_unit_headlight_link"/>
    <origin rpy="0 0 0" xyz="0 0 0"/>
  </joint>
  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
  <link name="left_diff_unit_taillight_link">
    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
  </link>
  <joint name="left_diff_unit_taillight_joint" type="fixed">
    <parent link="left_diff_unit_link"/>
    <child link="left_diff_unit_taillight_link"/>
    <origin rpy="0 0 0" xyz="0 0 0"/>
  </joint>
  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
  <link name="right_diff_unit_link">
    <inertial>
      <origin rpy="0 0 0" xyz="0 0.05 0.197"/>
      <mass value="50"/>
      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
    </inertial>
    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
  </link>
  <joint name="right_diff_unit_joint" type="fixed">
    <limit effort="100" lower="-0.4" upper="0.4" velocity="1"/>
    <parent link="chassis_link"/>
    <child link="right_diff_unit_link"/>
    <origin rpy="0 0 0" xyz="0.0 -0.56821 0.0"/>
    <axis xyz="0 1 0"/>
    <dynamics damping="100" friction="0.5"/>
  </joint>
  <link name="right_diff_unit_headlight_link">
    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
  </link>
  <joint name="right_diff_unit_headlight_joint" type="fixed">
    <parent link="right_diff_unit_link"/>
    <child link="right_diff_unit_headlight_link"/>
    <origin rpy="0 0 0" xyz="0 0 0"/>
  </joint>
  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
  <link name="right_diff_unit_taillight_link">
    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
  </link>
  <joint name="right_diff_unit_taillight_joint" type="fixed">
    <parent link="right_diff_unit_link"/>
    <child link="right_diff_unit_taillight_link"/>
    <origin rpy="0 0 0" xyz="0 0 0"/>
  </joint>
  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
  <link name="diff_link">
    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
  </link>
  <joint name="diff_link_joint" type="fixed">
    <parent link="chassis_link"/>
    <child link="diff_link"/>
    <origin rpy="0 0 0" xyz="-0.5826 0 0.24979"/>
  </joint>
  <link name="front_left_wheel_link">
    <inertial>
      <origin rpy="0 0 0" xyz="0 0 0"/>
      <mass value="15"/>
      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
    </inertial>
    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
  </link>
  <joint name="front_left_wheel_joint" type="fixed">
    <parent link="left_diff_unit_link"/>
    <child link="front_left_wheel_link"/>
    <origin rpy="0 0 0" xyz="0.457367 0.0 -0.012977"/>
    <axis xyz="0 1 0"/>
  </joint>
  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
  <link name="front_right_wheel_link">
    <inertial>
      <origin rpy="0 0 0" xyz="0 0 0"/>
      <mass value="15"/>
      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
    </inertial>
    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
  </link>
  <joint name="front_right_wheel_joint" type="fixed">
    <parent link="right_diff_unit_link"/>
    <child link="front_right_wheel_link"/>
    <origin rpy="0 0 0" xyz="0.457367 -0.0 -0.012977"/>
    <axis xyz="0 1 0"/>
  </joint>
  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
  <link name="rear_left_wheel_link">
    <inertial>
      <origin rpy="0 0 0" xyz="0 0 0"/>
      <mass value="15"/>
      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
    </inertial>
    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
  </link>
  <joint name="rear_left_wheel_joint" type="fixed">
    <parent link="left_diff_unit_link"/>
    <child link="rear_left_wheel_link"/>
    <origin rpy="0 0 0" xyz="-0.457367 0.0 -0.012977"/>
    <axis xyz="0 1 0"/>
  </joint>
  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
  <link name="rear_right_wheel_link">
    <inertial>
      <origin rpy="0 0 0" xyz="0 0 0"/>
      <mass value="15"/>
      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
    </inertial>
    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
  </link>
  <joint name="rear_right_wheel_joint" type="fixed">
    <parent link="right_diff_unit_link"/>
    <child link="rear_right_wheel_link"/>
    <origin rpy="0 0 0" xyz="-0.457367 -0.0 -0.012977"/>
    <axis xyz="0 1 0"/>
  </joint>
  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
  <link name="default_mount"/>
  <joint name="default_mount_joint" type="fixed">
    <origin rpy="0 0 0" xyz="0 0 0.27218"/>
    <parent link="chassis_link"/>
    <child link="default_mount"/>
  </joint>
  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
  <link name="imu_0_link">
    <inertial>
      <mass value="0.001"/>
      <origin rpy="0 0 0" xyz="0 0 0"/>
      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
    </inertial>
  </link>
  <joint name="imu_joint" type="fixed">
    <parent link="chassis_link"/>
    <child link="imu_0_link"/>
  </joint>
  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
  <ros2_control name="ur5e_hardware" type="system">
    <hardware>
      <plugin>mock_components/GenericSystem</plugin>
    </hardware>
    <joint name="arm_0_shoulder_pan_joint">
      <command_interface name="position"/>
      <state_interface name="position"/>
      <state_interface name="velocity"/>
    </joint>
    <joint name="arm_0_shoulder_lift_joint">
      <command_interface name="position"/>
      <state_interface name="position"/>
      <state_interface name="velocity"/>
    </joint>
    <joint name="arm_0_elbow_joint">
      <command_interface name="position"/>
      <state_interface name="position"/>
      <state_interface name="velocity"/>
    </joint>
    <joint name="arm_0_wrist_1_joint">
      <command_interface name="position"/>
      <state_interface name="position"/>
      <state_interface name="velocity"/>
    </joint>
    <joint name="arm_0_wrist_2_joint">
      <command_interface name="position"/>
      <state_interface name="position"/>
      <state_interface name="velocity"/>
    </joint>
    <joint name="arm_0_wrist_3_joint">
      <command_interface name="position"/>
      <state_interface name="position"/>
      <state_interface name="velocity"/>
    </joint>
  </ros2_control>
  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
  <link name="mount_frame_link">
    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
  </link>
  <joint name="mount_frame_joint" type="fixed">
    <parent link="default_mount"/>
    <child link="mount_frame_link"/>
    <origin rpy="0.0 0.0 0.0" xyz="0.0 0.0 0.0"/>
  </joint>
  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
  <link name="fath_pivot_0_link">
    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
  </link>
  <link name="fath_pivot_0_hinge_link">
    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
  </link>
  <link name="fath_pivot_0_mount"/>
  <joint name="fath_pivot_0_joint" type="fixed">
    <parent link="default_mount"/>
    <child link="fath_pivot_0_link"/>
    <origin rpy="0.0 1.5708 0.0" xyz="0.66692 0.0 0.07793"/>
  </joint>
  <joint name="fath_pivot_0_hinge_joint" type="fixed">
    <parent link="fath_pivot_0_link"/>
    <child link="fath_pivot_0_hinge_link"/>
    <origin rpy="0 -1.5708 0" xyz="0 0 0.0225"/>
  </joint>
  <joint name="fath_pivot_0_mount_joint" type="fixed">
    <parent link="fath_pivot_0_hinge_link"/>
    <child link="fath_pivot_0_mount"/>
    <origin rpy="0 0 0" xyz="0 0 0.0225"/>
  </joint>
  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
  <joint name="camera_0_joint" type="fixed">
    <origin rpy="0.0 0.0 0.0" xyz="0.0 0.0 0.0"/>
    <parent link="fath_pivot_0_mount"/>
    <child link="camera_0_bottom_screw_frame"/>
  </joint>
  <link name="camera_0_bottom_screw_frame"/>
  <joint name="camera_0_link_joint" type="fixed">
    <origin rpy="0 0 0" xyz="0.010600000000000002 0.0175 0.0125"/>
    <parent link="camera_0_bottom_screw_frame"/>
    <child link="camera_0_link"/>
  </joint>
  <link name="camera_0_link">
    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
    <inertial>
      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
      <mass value="0.072"/>
      <origin xyz="0 0 0"/>
      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
    </inertial>
  </link>
  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
  <link name="arm_0_base_link"/>
  <link name="arm_0_base_link_inertia">
    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
    <inertial>
      <mass value="4.0"/>
      <origin rpy="0 0 0" xyz="0 0 0"/>
      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
    </inertial>
  </link>
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

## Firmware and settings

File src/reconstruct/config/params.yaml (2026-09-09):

tree_point_cloud_reconstructor:
  ros__parameters:
    use_sim_time: false

    # Jetson / RealSense aligned RGB-D streams.
    color_topic: /sensors/camera_jetson/color/image_raw
    depth_topic: /sensors/camera_jetson/aligned_depth_to_color/image_raw
    camera_info_topic: /sensors/camera_jetson/aligned_depth_to_color/camera_info
    joint_state_topic: /joint_states

    # Capture transaction:
    #   request UInt32 N -> result Int32 +N accepted / -N rejected.
    capture_request_topic: /tree_scan/capture_request
    capture_result_topic: /tree_scan/capture_result
    scan_finished_topic: /tree_scan/scan_finished
    output_cloud_topic: /tree_scan/global_cloud
    original_cloud_topic: /tree_scan/latest_tf_cloud

    # Moving-arm reconstruction must use the robot fixed frame and exact sensor time.
    target_frame: base_link
    camera_frame_override: ""

    output_root: ~/dev/tree_scans
    # MUST be unique for every preflight, partial test, and complete scan.
    scan_id: outdoor_tree_6 
    capture_on_start: false

    sync_queue_size: 30
    sync_slop_sec: 0.08
    tf_timeout_sec: 0.75

    # Reject synchronizer frames buffered before the pose-specific request.
    post_request_guard_sec: 0.0
    # Warning only; measured age also contains transport latency.
    sensor_clock_warning_sec: 0.25

    # Five new frames are collected after motion success + settle.
    # Per-pixel median ignores zero depth; at least two nonzero observations
    # are required to keep a pixel.
    depth_burst_size: 5
    depth_burst_min_valid_samples: 2
    # A trajectory capture request remains at the same robot pose while the
    # reconstructor tries up to three independent fresh bursts. Rejected
    # attempts are saved but never merged. Only the final exhausted rejection
    # is published back to the trajectory node.
    capture_max_attempts: 3
    capture_retry_delay_sec: 0.25
    # Reject a burst if the exact-time camera TF shows meaningful motion.
    burst_pose_translation_tolerance_m: 0.005
    burst_pose_rotation_tolerance_deg: 0.5

    # D435-family conservative validity limits. The 3.5 m value matches the
    # final outdoor_tree_6 run; outdoor_tree_1 through _5 used 2.5 m.
    
    min_depth_m: 0.30
    max_depth_m: 3.50
    # 0 = auto: 1000 raw units/m for 16UC1, 1 for 32FC1.
    depth_scale_override: 0.0

    # Optional target-relative crop. Leave disabled until target distance and
    # broad box dimensions have been measured. In camera_forward mode, the
    # first accepted burst locks one center in base_link at +Z optical distance.
    target_crop_enabled: false
    target_center_mode: camera_forward  # camera_forward | fixed_target_frame
    target_distance_m: 1.0
    target_center_target_frame_m: [0.0, 0.0, 0.0]
    # Axis-aligned X/Y/Z dimensions in target_frame, not camera-frame pixels.
    target_box_size_m: [1.0, 1.0, 1.5]

    local_voxel_size_m: 0.003
    global_voxel_size_m: 0.003
    outlier_removal_enabled: true
    outlier_filter_mode: statistical  # none | radius | statistical
    outlier_radius_m: 0.020
    outlier_min_neighbors: 6
    statistical_nb_neighbors: 20
    statistical_std_ratio: 2.0

    use_icp: true
    icp_crop_margin_m: 0.15
    icp_min_target_points: 200
    # Retain the established limits until the camera extrinsic is validated.
    # Then evaluate approximately 0.03 m / 5 degrees against saved data.
    max_icp_correction_translation_m: 0.10
    max_icp_correction_rotation_deg: 12.0

    # Preserve each burst, zero-aware median, intrinsics, exact TF,
    # joint-state snapshot, and unfiltered PLY.
    save_raw_point_clouds: true
    publish_original_cloud: true
    shutdown_on_scan_finished: false

    registration:
      SN3:
        voxel_size_m: 0.05
        max_correspondence_distance_m: 0.05
        max_iterations: 50
        relative_rmse: 1.0e-6
        relative_fitness: 1.0e-6
        rmse_threshold_m: 0.025
        fitness_threshold: 0.35
      SN2:
        voxel_size_m: 0.02
        max_correspondence_distance_m: 0.03
        max_iterations: 30
        relative_rmse: 1.0e-6
        relative_fitness: 1.0e-6
        rmse_threshold_m: 0.015
        fitness_threshold: 0.40
      SN1:
        voxel_size_m: 0.01
        max_correspondence_distance_m: 0.018
        max_iterations: 20
        relative_rmse: 1.0e-6
        relative_fitness: 1.0e-6
        rmse_threshold_m: 0.010
        fitness_threshold: 0.45
      SN0:
        voxel_size_m: 0.0
        max_correspondence_distance_m: 0.012
        max_iterations: 15
        relative_rmse: 1.0e-6
        relative_fitness: 1.0e-6
        rmse_threshold_m: 0.008
        # Allow modestly lower final overlap for different/sparser trees while
        # retaining the 8 mm RMSE ceiling and ICP-correction sanity bounds.
        fitness_threshold: 0.45
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

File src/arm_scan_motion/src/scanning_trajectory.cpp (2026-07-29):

#include <rclcpp/rclcpp.hpp>
#include <rclcpp_action/rclcpp_action.hpp>
#include <control_msgs/action/follow_joint_trajectory.hpp>
#include <sensor_msgs/msg/joint_state.hpp>
#include <std_msgs/msg/bool.hpp>
#include <std_msgs/msg/int32.hpp>
#include <std_msgs/msg/u_int32.hpp>
#include <trajectory_msgs/msg/joint_trajectory.hpp>
#include <trajectory_msgs/msg/joint_trajectory_point.hpp>

#include <nlohmann/json.hpp>
#include <condition_variable>
#include <cstdint>
#include <fstream>
#include <iostream>
#include <limits>
#include <mutex>
#include <optional>
#include <string>
#include <vector>
#include <thread>
#include <chrono>
#include <cmath>
#include <map>

using json = nlohmann::json;

struct RecordedPoint {
  double time_from_start_sec;
  std::vector<double> positions;
  std::vector<double> velocities;
  std::vector<double> accelerations;
};

struct RecordedSegment {
  size_t step_index;
  std::string step_description;
  int pause_ms;
  std::vector<RecordedPoint> points;
};

bool load_recorded_json(const std::string& filepath,
                        std::vector<std::string>& joint_names,
                        std::vector<RecordedSegment>& segments,
                        std::string& error_msg)
{
  std::ifstream ifs(filepath);
  if (!ifs.is_open()) {
    error_msg = "Could not open JSON trajectory file: " + filepath;
    return false;
  }

  try {
    json j = json::parse(ifs);
    joint_names = j.at("joint_names").get<std::vector<std::string>>();

    for (const auto& seg_json : j.at("segments")) {
      RecordedSegment seg;
      seg.step_index = seg_json.at("step_index").get<size_t>();
      seg.step_description = seg_json.at("step_description").get<std::string>();
      seg.pause_ms = seg_json.at("pause_ms").get<int>();

      for (const auto& pt_json : seg_json.at("points")) {
        RecordedPoint rpt;
        rpt.time_from_start_sec = pt_json.at("time_from_start_sec").get<double>();
        rpt.positions = pt_json.at("positions").get<std::vector<double>>();
        if (pt_json.contains("velocities")) {
          rpt.velocities = pt_json.at("velocities").get<std::vector<double>>();
        }
        if (pt_json.contains("accelerations")) {
          rpt.accelerations = pt_json.at("accelerations").get<std::vector<double>>();
        }
        seg.points.push_back(rpt);
      }
      segments.push_back(seg);
    }
  } catch (const std::exception& e) {
    error_msg = std::string("JSON parsing error: ") + e.what();
    return false;
  }

  return true;
}

int main(int argc, char** argv)
{
  rclcpp::init(argc, argv);

  rclcpp::NodeOptions node_options;
  node_options.automatically_declare_parameters_from_overrides(true);
  auto node = std::make_shared<rclcpp::Node>("scanning_trajectory", node_options);

  if (!node->has_parameter("trajectory_input_path")) {
    node->declare_parameter<std::string>("trajectory_input_path", "recorded_scan_trajectory.json");
  }
  if (!node->has_parameter("max_steps")) {
    node->declare_parameter<int>("max_steps", 0);
  }
  if (!node->has_parameter("pause_ms")) {
    node->declare_parameter<int>("pause_ms", 300);
  }
  if (!node->has_parameter("capture_enabled")) {
    node->declare_parameter<bool>("capture_enabled", true);
  }
  if (!node->has_parameter("capture_request_topic")) {
    node->declare_parameter<std::string>(
      "capture_request_topic", "/tree_scan/capture_request");
  }
  if (!node->has_parameter("capture_result_topic")) {
    node->declare_parameter<std::string>(
      "capture_result_topic", "/tree_scan/capture_result");
  }
  if (!node->has_parameter("scan_finished_topic")) {
    node->declare_parameter<std::string>(
      "scan_finished_topic", "/tree_scan/scan_finished");
  }
  if (!node->has_parameter("capture_settle_time_ms")) {
    node->declare_parameter<int>("capture_settle_time_ms", 1000);
  }
  if (!node->has_parameter("capture_timeout_sec")) {
    node->declare_parameter<double>("capture_timeout_sec", 15.0);
  }
  if (!node->has_parameter("capture_subscriber_timeout_sec")) {
    node->declare_parameter<double>("capture_subscriber_timeout_sec", 15.0);
  }
  if (!node->has_parameter("abort_on_capture_rejection")) {
    node->declare_parameter<bool>("abort_on_capture_rejection", true);
  }
  if (!node->has_parameter("trajectory_timeout_scale")) {
    node->declare_parameter<double>("trajectory_timeout_scale", 10.0);
  }
  if (!node->has_parameter("trajectory_timeout_margin_sec")) {
    node->declare_parameter<double>("trajectory_timeout_margin_sec", 10.0);
  }

  std::string input_path = node->get_parameter("trajectory_input_path").as_string();
  int max_steps = node->get_parameter("max_steps").as_int();
  int override_pause_ms = node->get_parameter("pause_ms").as_int();
  bool capture_enabled = node->get_parameter("capture_enabled").as_bool();
  std::string capture_request_topic =
    node->get_parameter("capture_request_topic").as_string();
  std::string capture_result_topic =
    node->get_parameter("capture_result_topic").as_string();
  std::string scan_finished_topic =
    node->get_parameter("scan_finished_topic").as_string();
  int capture_settle_time_ms =
    node->get_parameter("capture_settle_time_ms").as_int();
  double capture_timeout_sec =
    node->get_parameter("capture_timeout_sec").as_double();
  double capture_subscriber_timeout_sec =
    node->get_parameter("capture_subscriber_timeout_sec").as_double();
  bool abort_on_capture_rejection =
    node->get_parameter("abort_on_capture_rejection").as_bool();
  double trajectory_timeout_scale =
    node->get_parameter("trajectory_timeout_scale").as_double();
  double trajectory_timeout_margin_sec =
    node->get_parameter("trajectory_timeout_margin_sec").as_double();

  if (capture_settle_time_ms < 0 || capture_timeout_sec <= 0.0 ||
      capture_subscriber_timeout_sec <= 0.0 ||
      trajectory_timeout_scale <= 0.0 ||
      trajectory_timeout_margin_sec < 0.0) {
    RCLCPP_ERROR(
      node->get_logger(),
      "Capture/trajectory timeout parameters are invalid.");
    rclcpp::shutdown();
    return 1;
  }

  auto trajectory_result_timeout = [
    trajectory_timeout_scale,
    trajectory_timeout_margin_sec
  ](double nominal_duration_sec) {
    return std::chrono::duration<double>(
      nominal_duration_sec * trajectory_timeout_scale +
      trajectory_timeout_margin_sec);
  };

  rclcpp::executors::SingleThreadedExecutor executor;
  executor.add_node(node);
  std::thread spinner([&executor]() { executor.spin(); });

  std::mutex capture_mutex;
  std::condition_variable capture_cv;
  std::optional<int32_t> latest_capture_result;

  auto capture_qos = rclcpp::QoS(rclcpp::KeepLast(10)).reliable();
  auto capture_request_pub =
    node->create_publisher<std_msgs::msg::UInt32>(
      capture_request_topic, capture_qos);
  auto capture_result_sub =
    node->create_subscription<std_msgs::msg::Int32>(
      capture_result_topic,
      capture_qos,
      [&capture_mutex, &capture_cv, &latest_capture_result](
        const std_msgs::msg::Int32::SharedPtr msg) {
        {
          std::lock_guard<std::mutex> lock(capture_mutex);
          latest_capture_result = msg->data;
        }
        capture_cv.notify_all();
      });
  auto scan_finished_pub =
    node->create_publisher<std_msgs::msg::Bool>(
      scan_finished_topic, capture_qos);

  auto wait_for_capture_pipeline = [&]() -> bool {
    if (!capture_enabled) {
      return true;
    }

    const auto deadline =
      std::chrono::steady_clock::now() +
      std::chrono::duration<double>(capture_subscriber_timeout_sec);
    while (rclcpp::ok() && std::chrono::steady_clock::now() < deadline) {
      if (capture_request_pub->get_subscription_count() > 0 &&
          capture_result_sub->get_publisher_count() > 0) {
        RCLCPP_INFO(
          node->get_logger(),
          "Capture pipeline connected on '%s' / '%s'.",
          capture_request_topic.c_str(), capture_result_topic.c_str());
        return true;
      }
      std::this_thread::sleep_for(std::chrono::milliseconds(100));
    }

    RCLCPP_ERROR(
      node->get_logger(),
      "Capture pipeline was not connected within %.1f s. "
      "Start the reconstructor first or set capture_enabled:=false.",
      capture_subscriber_timeout_sec);
    return false;
  };

  auto request_capture = [&](uint32_t request_id) -> bool {
    if (!capture_enabled) {
      return true;
    }
    if (request_id == 0 ||
        request_id > static_cast<uint32_t>(std::numeric_limits<int32_t>::max())) {
      RCLCPP_ERROR(node->get_logger(), "Invalid capture request id: %u", request_id);
      return false;
    }

    {
      std::lock_guard<std::mutex> lock(capture_mutex);
      latest_capture_result.reset();
    }

    std_msgs::msg::UInt32 request;
    request.data = request_id;
    capture_request_pub->publish(request);
    RCLCPP_INFO(
      node->get_logger(),
      "Capture %u requested after %d ms settle time; waiting for result...",
      request_id, capture_settle_time_ms);

    std::unique_lock<std::mutex> lock(capture_mutex);
    const bool received = capture_cv.wait_for(
      lock,
      std::chrono::duration<double>(capture_timeout_sec),
      [&latest_capture_result, request_id]() {
        if (!latest_capture_result.has_value()) {
          return false;
        }
        const int64_t value = static_cast<int64_t>(*latest_capture_result);
        const uint32_t result_id =
          static_cast<uint32_t>(value < 0 ? -value : value);
        return result_id == request_id;
      });

    if (!received) {
      RCLCPP_ERROR(
        node->get_logger(),
        "Capture %u timed out after %.1f s.", request_id, capture_timeout_sec);
      return false;
    }

    const bool accepted = *latest_capture_result > 0;
    if (accepted) {
      RCLCPP_INFO(node->get_logger(), "Capture %u accepted.", request_id);
      return true;
    }

    if (abort_on_capture_rejection) {
      RCLCPP_ERROR(
        node->get_logger(),
        "Capture %u was rejected; stopping before the next motion.", request_id);
      return false;
    }

    RCLCPP_WARN(
      node->get_logger(),
      "Capture %u was rejected; continuing because "
      "abort_on_capture_rejection=false.",
      request_id);
    return true;
  };

  std::vector<std::string> joint_names;
  std::vector<RecordedSegment> segments;
  std::string err_msg;

  if (!load_recorded_json(input_path, joint_names, segments, err_msg)) {
    RCLCPP_ERROR(node->get_logger(), "Failed to load trajectory: %s", err_msg.c_str());
    executor.cancel();
    if (spinner.joinable()) spinner.join();
    rclcpp::shutdown();
    return 1;
  }

  if (segments.empty()) {
    RCLCPP_ERROR(node->get_logger(), "Trajectory file is empty.");
    executor.cancel();
    if (spinner.joinable()) spinner.join();
    rclcpp::shutdown();
    return 1;
  }

  size_t active_segments = (max_steps > 0 && static_cast<size_t>(max_steps) < segments.size())
                           ? static_cast<size_t>(max_steps)
                           : segments.size();

  RCLCPP_INFO(node->get_logger(), "Loaded scanning trajectory: %zu steps (%zu joints, input: '%s').",
              active_segments, joint_names.size(), input_path.c_str());

  using FollowJointTrajectory = control_msgs::action::FollowJointTrajectory;
  auto action_client = rclcpp_action::create_client<FollowJointTrajectory>(
    node, "/joint_trajectory_controller/follow_joint_trajectory");

  if (!action_client->wait_for_action_server(std::chrono::seconds(5))) {
    RCLCPP_ERROR(node->get_logger(), "Action server unavailable.");
    executor.cancel();
    if (spinner.joinable()) spinner.join();
    rclcpp::shutdown();
    return 1;
  }

  if (!wait_for_capture_pipeline()) {
    executor.cancel();
    if (spinner.joinable()) spinner.join();
    rclcpp::shutdown();
    return 1;
  }

  sensor_msgs::msg::JointState::SharedPtr latest_joint_state;
  auto joint_state_sub = node->create_subscription<sensor_msgs::msg::JointState>(
    "/joint_states", 10,
    [&latest_joint_state](const sensor_msgs::msg::JointState::SharedPtr msg) {
      latest_joint_state = msg;
    });

  auto start_wait = std::chrono::steady_clock::now();
  while (rclcpp::ok() && !latest_joint_state) {
    if (std::chrono::steady_clock::now() - start_wait > std::chrono::seconds(5)) break;
    std::this_thread::sleep_for(std::chrono::milliseconds(100));
  }

  if (!latest_joint_state) {
    RCLCPP_ERROR(node->get_logger(), "Failed to receive /joint_states within 5 seconds.");
    executor.cancel();
    if (spinner.joinable()) spinner.join();
    rclcpp::shutdown();
    return 1;
  }

  std::map<std::string, double> current_positions;
  for (size_t i = 0; i < latest_joint_state->name.size(); ++i) {
    if (i < latest_joint_state->position.size()) {
      current_positions[latest_joint_state->name[i]] = latest_joint_state->position[i];
    }
  }

  const auto& expected_start_pt = segments[0].points[0];
  double max_allowed_start_diff_deg = 5.0;
  double max_allowed_start_diff_rad = max_allowed_start_diff_deg * M_PI / 180.0;
  bool start_pose_ok = true;
  double max_found_diff_deg = 0.0;

  for (size_t j = 0; j < joint_names.size(); ++j) {
    const std::string& j_name = joint_names[j];
    if (current_positions.find(j_name) == current_positions.end()) {
      RCLCPP_ERROR(node->get_logger(), "Joint '%s' missing from /joint_states.", j_name.c_str());
      start_pose_ok = false;
      break;
    }

    double cur_pos_rad = current_positions[j_name];
    double exp_pos_rad = expected_start_pt.positions[j];
    double diff_deg = std::abs(cur_pos_rad - exp_pos_rad) * 180.0 / M_PI;
    max_found_diff_deg = std::max(max_found_diff_deg, diff_deg);

    if (diff_deg > max_allowed_start_diff_deg) {
      start_pose_ok = false;
    }
  }

  // Move to Home if robot is away from Home pose
  if (!start_pose_ok) {
    std::cout << "\nRobot is NOT at HOME pose (Max diff: " << max_found_diff_deg << " deg).\n"
              << "Type 'yes' and press Enter to smoothly move arm to HOME pose first: " << std::flush;

    std::string user_input_home;
    std::getline(std::cin, user_input_home);
    if (user_input_home != "yes") {
      RCLCPP_WARN(node->get_logger(), "Initial move-to-home aborted.");
      executor.cancel();
      if (spinner.joinable()) spinner.join();
      rclcpp::shutdown();
      return 0;
    }

    FollowJointTrajectory::Goal move_home_goal;
    move_home_goal.trajectory.joint_names = joint_names;

    double home_move_dur = 5.0;
    int num_pts = 25;

    std::vector<double> start_vec;
    for (size_t j = 0; j < joint_names.size(); ++j) {
      start_vec.push_back(current_positions[joint_names[j]]);
    }

    for (int i = 0; i <= num_pts; ++i) {
      double t = home_move_dur * (static_cast<double>(i) / num_pts);
      double s = 0.5 * (1.0 - std::cos(M_PI * t / home_move_dur));
      double s_dot = (M_PI / (2.0 * home_move_dur)) * std::sin(M_PI * t / home_move_dur);

      trajectory_msgs::msg::JointTrajectoryPoint pt;
      pt.positions.resize(joint_names.size());
      pt.velocities.resize(joint_names.size(), 0.0);
      pt.accelerations.resize(joint_names.size(), 0.0);

      for (size_t j = 0; j < joint_names.size(); ++j) {
        double delta = expected_start_pt.positions[j] - start_vec[j];
        pt.positions[j] = start_vec[j] + s * delta;
        pt.velocities[j] = s_dot * delta;
      }
      pt.time_from_start = rclcpp::Duration::from_seconds(t);
      move_home_goal.trajectory.points.push_back(pt);
    }

    RCLCPP_INFO(node->get_logger(), "Moving arm to HOME pose (5.0s)...");
    auto send_goal_options = rclcpp_action::Client<FollowJointTrajectory>::SendGoalOptions();
    auto goal_handle_future = action_client->async_send_goal(move_home_goal, send_goal_options);

    if (goal_handle_future.wait_for(std::chrono::seconds(5)) != std::future_status::ready) {
      RCLCPP_ERROR(node->get_logger(), "Move to HOME failed.");
      executor.cancel();
      if (spinner.joinable()) spinner.join();
      rclcpp::shutdown();
      return 1;
    }

    auto home_goal_handle = goal_handle_future.get();
    if (!home_goal_handle) {
      RCLCPP_ERROR(node->get_logger(), "Move to HOME goal was rejected.");
      executor.cancel();
      if (spinner.joinable()) spinner.join();
      rclcpp::shutdown();
      return 1;
    }

    auto result_future = action_client->async_get_result(home_goal_handle);
    if (result_future.wait_for(trajectory_result_timeout(home_move_dur)) !=
        std::future_status::ready) {
      auto cancel_future = action_client->async_cancel_goal(home_goal_handle);
      cancel_future.wait_for(std::chrono::seconds(2));
      RCLCPP_ERROR(node->get_logger(), "Move to HOME timed out and was canceled.");
      executor.cancel();
      if (spinner.joinable()) spinner.join();
      rclcpp::shutdown();
      return 1;
    }
    if (result_future.get().code != rclcpp_action::ResultCode::SUCCEEDED) {
      RCLCPP_ERROR(node->get_logger(), "Move to HOME execution failed.");
      executor.cancel();
      if (spinner.joinable()) spinner.join();
      rclcpp::shutdown();
      return 1;
    }

    RCLCPP_INFO(node->get_logger(), "Arrived at HOME pose.");
  }

  std::cout << "\nExecute hardcoded scanning replay (" << active_segments << " steps)? Type 'yes': " << std::flush;
  std::string user_input;
  std::getline(std::cin, user_input);
  if (user_input != "yes") {
    RCLCPP_WARN(node->get_logger(), "Replay aborted.");
    executor.cancel();
    if (spinner.joinable()) spinner.join();
    rclcpp::shutdown();
    return 0;
  }

  bool replay_ok = true;
  
  constexpr double trajectory_lead_in_sec = 0.25;

  for (size_t k = 0; k < active_segments; ++k) {
    if (!rclcpp::ok()) {
      replay_ok = false;
      break;
    }

    const auto& seg = segments[k];
    int cur_pause_ms = (override_pause_ms > 0) ? override_pause_ms : seg.pause_ms;
    std::this_thread::sleep_for(std::chrono::milliseconds(cur_pause_ms));

    if (!rclcpp::ok()) break;

    FollowJointTrajectory::Goal goal;
    goal.trajectory.joint_names = joint_names;

    for (const auto& rpt : seg.points) {
      trajectory_msgs::msg::JointTrajectoryPoint pt;
      pt.positions = rpt.positions;
      pt.velocities = rpt.velocities;
      pt.accelerations = rpt.accelerations;
      pt.time_from_start = rclcpp::Duration::from_seconds(trajectory_lead_in_sec + rpt.time_from_start_sec);
      goal.trajectory.points.push_back(pt);
    }

    double seg_duration = seg.points.empty()
      ? 0.0
      : trajectory_lead_in_sec + seg.points.back().time_from_start_sec;
    RCLCPP_INFO(node->get_logger(), "[Step %zu/%zu] %s", k + 1, active_segments, seg.step_description.c_str());

    auto send_goal_options = rclcpp_action::Client<FollowJointTrajectory>::SendGoalOptions();
    auto goal_handle_future = action_client->async_send_goal(goal, send_goal_options);

    if (goal_handle_future.wait_for(std::chrono::seconds(5)) != std::future_status::ready) {
      RCLCPP_ERROR(node->get_logger(), "[Step %zu/%zu] Send failed.", k + 1, active_segments);
      replay_ok = false;
      break;
    }

    auto goal_handle = goal_handle_future.get();
    if (!goal_handle) {
      RCLCPP_ERROR(
        node->get_logger(), "[Step %zu/%zu] Goal rejected.",
        k + 1, active_segments);
      replay_ok = false;
      break;
    }

    auto result_future = action_client->async_get_result(goal_handle);
    if (result_future.wait_for(trajectory_result_timeout(seg_duration)) !=
        std::future_status::ready) {
      auto cancel_future = action_client->async_cancel_goal(goal_handle);
      cancel_future.wait_for(std::chrono::seconds(2));
      RCLCPP_ERROR(
        node->get_logger(),
        "[Step %zu/%zu] Execution timed out and was canceled.",
        k + 1, active_segments);
      replay_ok = false;
      break;
    }
    if (result_future.get().code != rclcpp_action::ResultCode::SUCCEEDED) {
      RCLCPP_ERROR(node->get_logger(), "[Step %zu/%zu] Execution failed.", k + 1, active_segments);
      replay_ok = false;
      break;
    }

    std::this_thread::sleep_for(
      std::chrono::milliseconds(capture_settle_time_ms));
    if (!request_capture(static_cast<uint32_t>(k + 1))) {
      replay_ok = false;
      break;
    }
  }

  // Smooth final return to Home pose at the end of scanning
  if (replay_ok && active_segments == segments.size() && rclcpp::ok()) {
    const auto& home_positions = segments[0].points[0].positions;
    const auto& last_segment_pts = segments.back().points;
    if (!last_segment_pts.empty()) {
      const auto& current_end_positions = last_segment_pts.back().positions;
      double max_dist_to_home = 0.0;
      for (size_t j = 0; j < home_positions.size(); ++j) {
        max_dist_to_home = std::max(max_dist_to_home, std::abs(current_end_positions[j] - home_positions[j]));
      }

      if (max_dist_to_home > 0.0175) {
        RCLCPP_INFO(node->get_logger(), "Returning arm to HOME pose...");
        std::this_thread::sleep_for(std::chrono::milliseconds(300));

        FollowJointTrajectory::Goal home_goal;
        home_goal.trajectory.joint_names = joint_names;

        double return_dur = 3.5;
        int num_pts = 20;

        for (int i = 0; i <= num_pts; ++i) {
          double t = return_dur * (static_cast<double>(i) / num_pts);
          double s = 0.5 * (1.0 - std::cos(M_PI * t / return_dur));
          double s_dot = (M_PI / (2.0 * return_dur)) * std::sin(M_PI * t / return_dur);

          trajectory_msgs::msg::JointTrajectoryPoint pt;
          pt.positions.resize(home_positions.size());
          pt.velocities.resize(home_positions.size(), 0.0);
          pt.accelerations.resize(home_positions.size(), 0.0);
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

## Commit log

2026-07-20 Imported reconstruction algorithm from PhD student Dawood Ahmed. In progress of refactoring to output .dae or .stl 3D files.
2026-07-21 refactor: migrate tree scanning pipeline to ROS2 Humble/Gazebo Fortress
    - Port motion planner from rospy to rclpy
    - Port RGB-D reconstruction pipeline to ROS2
    - Replace ROS1 TF/action APIs with TF2 and ROS2 actions
    - Update camera topics for UR5e Jetson camera
    - Add ROS2 package, launch, and parameter files
    - Fix reconstruction bugs and capture synchronization
    - Improve scan workflow and PLY generation
    [params.yaml]
2026-07-22 docs: consolidate project history and reconstruction planning
    * add archived pre-pivot charter and handoff questions
    * import logbook notes from July 16–22
    * document inherited work, provenance, and migration status
    * add reconstruction evaluation criteria, metrics, scenarios, and protocol
    * update the active project charter for the ROS 2 tree-scanning scope
    * refine reconstruction parameters for the current indoor scan workflow
2026-07-27 feat(reconstruct): add robust pose-synchronized RGB-D capture
    - introduce request/result capture handshaking and zero-aware depth bursts
    - save raw captures, exact TF, intrinsics, joint states, and run metadata
    - add target-relative cropping and configurable outlier filtering
    - separate reconstruction launch from trajectory execution
2026-07-27 feat(reconstruct): add TF-only registration evaluation
    Compare TF-only and TF+ICP replays on identical captures, log per-frame
    ICP corrections and closure errors, generate diagnostic plots, and reduce
    the default reconstruction voxel size to 3 mm.
    [params.yaml]
2026-07-29 Import UR5e motion and MoveIt packages from Dawood workspace
    [electric_pruner.stl, joint_limits.yaml, mount_frame.STL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]
